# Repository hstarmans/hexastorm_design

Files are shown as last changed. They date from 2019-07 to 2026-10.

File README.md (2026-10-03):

# Hexastorm: Laser Scanner CAD

FreeCAD design files for **Hexastorm**, an open-hardware polygon laser direct imager (LDI) for PCB lithography and laser scanning.

* **Documentation & Theory**: [Open hardware fast high resolution laser (RepRap Wiki)](https://reprap.org/wiki/Open_hardware_fast_high_resolution_LASER)
* **Electronics & Firmware**: [firestarter (GitHub)](https://github.com/hstarmans/firestarter)
* **Optical Simulation**: [opticaldesign (GitHub)](https://github.com/hstarmans/opticaldesign)

<p align="center">
  Hexastorm Base Configuration (without cylinder lenses)
  Hexastorm with Cylinder Lenses
  <br>
  <em>Left: Base configuration (no cylinder lenses). Right: Configuration with CL1 saddle bridge and CL2 lens.</em>
</p>

---

## Design Overview

* **Optical Configurations (Base vs. Cylinder Lens Upgrade)**:

  * **Base (no cylinder lenses)**: Focussed beam goes directly from the laser diode through the polygon prism into a small spot. Lower component count, but results in an elliptical beam spot.
  * **With Cylinder Lenses**: Adding CL1 (mounted in saddle bridge `sk_bridge_pcb`) and CL2 circularizes the beam spot and optically cancels facet tilt errors from the rotating prism. The beam is collimated when it leaves the laserdiode.
* **Prism Drive & Motor Support**:

  * Typically, a refurbished sharp AR160 polygon mirror motor is used.
  * However, a  PCB motor (`mirrormotor.FCStd` / `pcbmotorasm`) with stator coils etched into PCB copper (driven by [firestarter](https://github.com/hstarmans/firestarter)) can also be used for laser scanning.

<p align="center">
  Hexastorm Planar PCB Motor and Internal Layout
</p>

* **Chassis**: Tab-and-slot FR4 PCB panels soldered at the seams.
* **Maxwell Kinematic Dock**:
  * Toolhead mount using 3 radial V-grooves on the scanhead PCB mating with 3 captive Ø 8.0 mm steel bearing balls on the dock base.
  * Clamped by 3 pairs of Ø 8.0 mm × 1.0 mm N52 magnets (~17 N pull, 0.40 mm magnet air gap).
  * PCB separation is 2.40 mm when docked.
  * Mates with [maxwell_dock.kicad_pcb](file:///home/hexastorm/Documents/hardware/firestarter/lasermodule/maxwell_dock/maxwell_dock/maxwell_dock.kicad_pcb). Mounting to a CNC 3018 or extrusion frame requires an adapter plate.

<p align="center">
  Hexastorm Maxwell Kinematic Dock Interface
</p>

* **KiCad Integration**: Board outlines and aperture cutouts in FreeCAD sync directly to KiCad `Edge.Cuts` via KiCad StepUp.

---

## Repository Structure

```text
├── FreeCAD files/
│   ├── assembly_compact_new.FCStd   # Main assembly (FreeCAD 1.0)
│   ├── mirrormotor.FCStd            # Polygon prism and PCB motor assembly
│   └── ArducamUC621/                # Calibration & profiling fixtures
├── Images/
│   ├── freecadpic_base.png          # Base configuration (no cylinder lenses)
│   ├── freecadpic.png               # Configuration with cylinder lenses
│   ├── pcb_motor_view.png           # Internal layout with planar PCB motor and rotor
│   └── kinematic_dock_view.png      # Kinematic dock underside view
├── AGENTS.md                        # CAD assistant & pair-programming guidelines
└── README.md
```

---

## CAD Environment

### 1. Git LFS

This repository stores `.FCStd` files and images in Git LFS. Run before cloning:

```bash
git lfs install
git clone https://github.com/hstarmans/hexastorm_design.git
```

*(If cloned without LFS, run `git lfs pull` inside the repository).*

### 2. FreeCAD Requirements

* **FreeCAD**: 1.0 or higher.
* **Workbenches**:
  * Assembly (built-in FreeCAD 1.0)
  * PartDesign
  * Fasteners Workbench
  * KiCad StepUp

---

## Optical Simulation & Ray Tracing

Ray tracing and optical verification are handled by [opticaldesign](https://github.com/hstarmans/opticaldesign) (`pyoptools` and `prisms.cad_verifier`).

Run with FreeCAD open:

```bash
cd path/to/opticaldesign
uv run python -m prisms.cad_verifier
```

This traces rays through the diode, lenses, polygon facets, and mirror, and writes rays into FreeCAD under `Simulation/Rays`.

---

## Reference Videos

* [Assembly 4 Design Overview (Legacy)](https://youtu.be/jhr6iEazbQk)
* [Optical Simulation Walkthrough](https://youtu.be/kekMkjqzRjE)

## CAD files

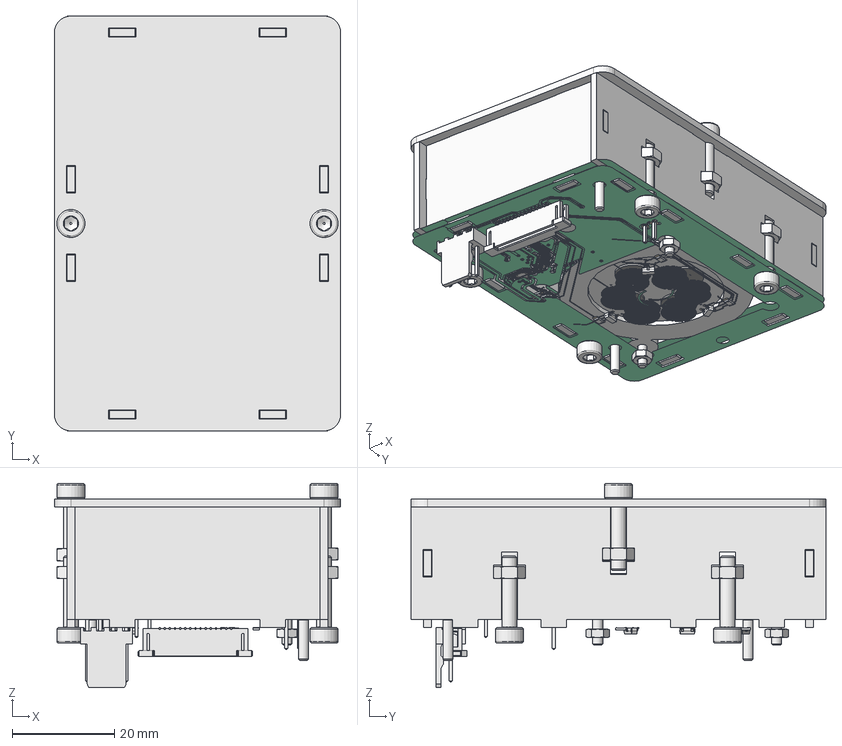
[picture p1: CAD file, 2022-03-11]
FreeCAD files/assembly_compact.FCStd
56.0 x 81.2 x 39.9 mm
M2x8-Screw066
M2x8-Screw067
topPads_87
topTracks_87
topZones_87
botPads_87
botTracks_87
botZones_87
C1_C_0805_2012Metric_00005d37801c x 9
J6_Molex_AE_6410_02A_00005d378133
R2_R_0805_2012Metric_00005d37818e x 15
U1_DFN-8-1EP_2x2mm_Pitch0.5mm_00005d3781c2
U2_CircuitWorks-SO-8_00005d3781d2
F2_Fuse_1206_3216Metric_000060f6f7c8 x 3
U5_SOT_353_SC_70_5_8d7aa654a458 x 2
U3_UQFN-16-1EP_3x3mm_Pitch0.5mm_772bcda8c549
J2_C-1-1734248-5_000060f44a9a
J1_Molex_AE_6410_04A_5e5622cabe99
U6_SOT_23_ee3f73b8ded8 x 3
M3x14-Screw1328
M3x14-Screw1329
M3x14-Screw1330
M3x14-Screw1331
M3-Nut1678
M3-Nut1675
M3-Nut1677
M3-Nut1676
support_body
M2x14-Screw
M2x14-Screw001
M2-Nut858
M2-Nut859
prismbody
spacersolid
laserdiodebasesolid
laserdiodebackplatesolid
M2x8-Screw
M2x8-Screw008
M2x8-Screw007
M2x8-Screw006
ringsolid
PadBody
magnet007 x 4
D1_BPW_34_S_20180209_geometry_000060f4e1a5
J1_PinHeader_1x02_P254mm_Horizontal_915322ff12bd
Pcb_323e002
rightside_plate x 2
back_plate
front_plate
PocketBody002
M3x14-Screw1322
M3x14-Screw1323
M3-Nut
M3-Nut1670

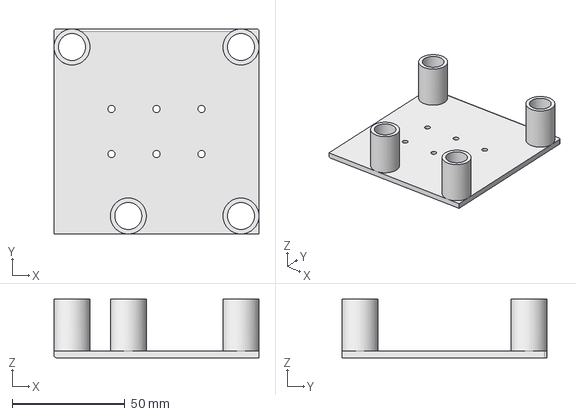
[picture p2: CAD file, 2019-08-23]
FreeCAD files/felix_mount.FCStd
91.0 x 91.0 x 26.0 mm

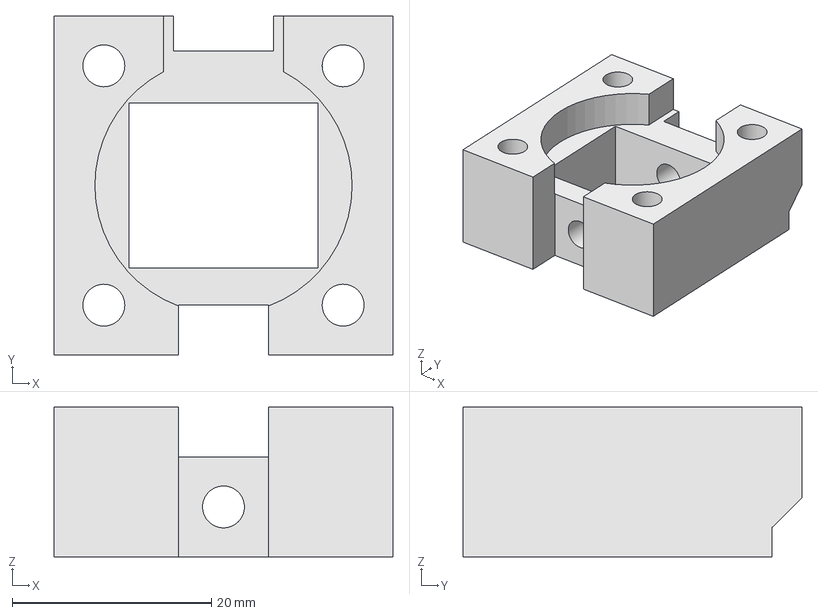
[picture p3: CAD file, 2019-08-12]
FreeCAD files/ueye_front.FCStd
34.0 x 34.0 x 15.0 mm

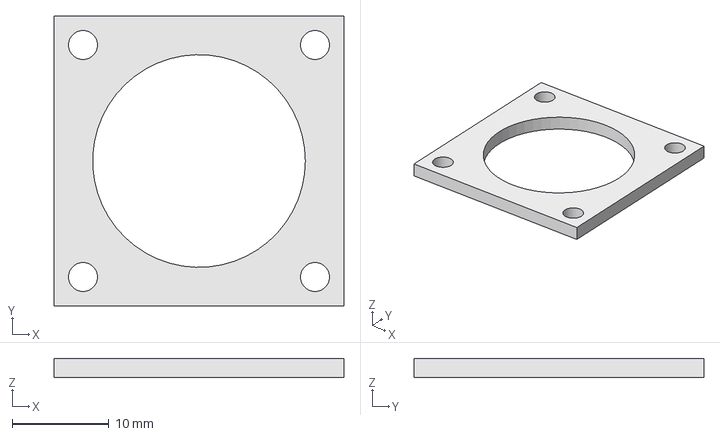
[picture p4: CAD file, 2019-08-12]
FreeCAD files/ueye_cap.FCStd
30.0 x 30.0 x 2.00 mm

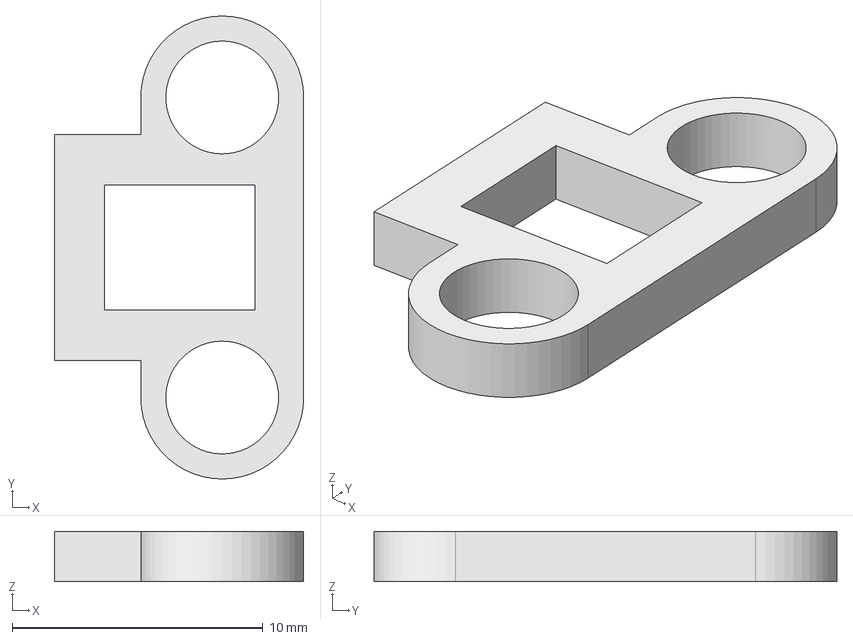
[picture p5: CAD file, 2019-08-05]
FreeCAD files/photodiode_cap.FCStd
9.95 x 18.5 x 2.00 mm

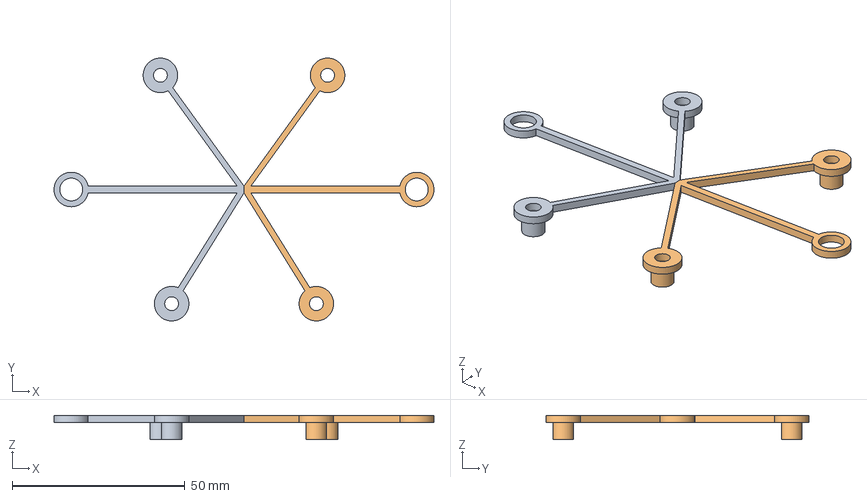
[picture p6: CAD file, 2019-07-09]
FreeCAD files/beaglebone_fixture.FCStd
110.0 x 76.1 x 7.00 mm
Pad002 (Mirror #1)

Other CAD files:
FreeCAD files/ArducamUC621/lensassembly.FCStd
FreeCAD files/assembly_compact_new.FCStd
FreeCAD files/cnc3018_case.FCStd
FreeCAD files/ArducamUC621/arducamUC621base.FCStd
FreeCAD files/cnc3018_pro.FCStd
FreeCAD files/ArducamUC621/ueye_postholder.FCStd
FreeCAD files/mirrormotor.FCStd
renders/hexastorm_assembly.blend

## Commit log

2019-06-05 added current repository of freecad design files, stls and solidpython
    [bovenkant.fcstd, onderkant.fcstd]
2019-06-05 added stls
    added stls made with solidedge
    [aspheric_25mm_mount.stl, aspheric_75mm_mount.stl, baseplate.stl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]
2019-06-06 added standoff design and considerations
    [standoff.FCStd]
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2019-06-12 added start baseplate
    [baseplate.FCStd]
2019-06-17 added aspherical lens1
    [aspherical_lens1.FCStd, baseplate.FCStd, standoff_polygonmirror.FCStd]
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2019-06-18 added sketch lens2
    [aspherical_lens2.FCStd]
2019-06-18 added aspherical lens with mirror holder
    [aspherical_lens2.FCStd]
2019-06-18 added photodiode cap and holder
    [photodiode_cap.FCStd, photodiode_holder.FCStd]
2019-06-19 updated cylindrical lens 1
    [aspherical_lens1.FCStd, cylindrical_lens1.FCStd]
2019-06-19 changed second cylindrical lens
    [cylindrical_lens2.FCStd]
2019-06-19 removed lens
    [aspherical_lens2.FCStd]
2019-06-19 prepared baseplate and standoff for first test
    [baseplate.FCStd, cylindrical_lens1.FCStd, standoff_polygonmirror.FCStd]
2019-06-20 height laserdiode should be set from the top
    [baseplate.FCStd, ofl510v3_support.FCStd, standoff_polygonmirror.FCStd]
2019-06-27 made some major changes to cylindrical lens2
    still needs testing
    [baseplate.FCStd, cylindrical_lens1.FCStd, cylindrical_lens2_trial2.FCStd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]
2019-07-09 added atx holders, fixture and modified baseplate
    [atxholder_back.FCStd, atxholder_front.FCStd, baseplate.FCStd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]
2019-07-24 updated bom list and added standoff board
    [standoff_alignmentboard.FCStd]
2019-07-24 added new base for photodiode and modified cylindrical lens so it can be positioned
    [cylindrical_lens2.FCStd, cylindrical_lens2_trial2.FCStd, photodiode_base.FCStd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]
2019-08-05 added latest changes, second cylindrical lens holder should have correct dimensions
    [cylindrical_lens2_trial2.FCStd, photodiode_base.FCStd, photodiode_cap.FCStd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]
2019-08-12 updated designs
    [cylindrical_lens2_trial2.FCStd, ueye_cap.FCStd, ueye_front.FCStd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]
2019-08-19 started maxing enclosure suitable for laser cutting
    [assembly.FCStd, back.step, back_module.FCStd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]
2019-08-19 modified box, too few room to move first cylindrical lens
    [assembly.FCStd, bottem.step, box_2.FCStd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]
2019-08-20 forgot to save latest changes
    [box_2.FCStd]
2019-08-22 added mount to felixprinter, changed height lasertube
    [felix_mount.FCStd, lasertube_support.FCStd]
2019-08-23 enlarged internal diameter felixmount to 6 mm
    [felix_mount.FCStd]
2019-08-23 updated box
    [box_2.FCStd]
2019-09-16 changed basepost
    [photodiode_basepostm6.FCStd]
2019-09-18 cleaned up repository for hackaday 2019 semi-finals
    [aspheric_25mm_mount.stl, aspheric_75mm_mount.stl, assembly.FCStd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]
2019-10-21 fixed thickness
    [box_2.FCStd]
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2020-08-17 added fixture for rasp
    [raspberry_fixture.FCStd]
2020-12-15 improved box
    [assembly.FCStd, assembly_interlock.FCStd, back.step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]
2020-12-18 updated box, improved assembly
    most parts are now maintaned in assembly
    [arducamUC621base.FCStd, arducamUC621lensholder.FCStd, assembly.FCStd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]
2020-12-18 removed steps
    [back.step, bottem.step, front.step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]
2020-12-18 removed screwbase
    [screwbase2_cylinderlens1.FCStd, screwbase_cylinderlens1.FCStd]
2021-01-05 created assembly
    [48353.FCStd, arducamUC621base.FCStd, arducamUC621lensholder.FCStd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]
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2021-06-20 added optical simulations
    [fullassembly.FCStd]
2021-07-28 updated assemlby
    [fullassembly.FCStd]
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2021-08-04 updated simulation and improved positions
    [fullassembly.FCStd]
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2021-08-06 reduced width of assembly
    might crash in optical simulation, still needs to be checked
    [fullassembly.FCStd]
2021-09-02 added new laser diode module
    [fullassembly.FCStd]
2021-09-04 fixed top
    [fullassembly.FCStd]
2021-09-05 updated assembly and design
    [fullassembly.FCStd]
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2021-10-05 alignment tool used for mounting prism assembly reduced in size, cross scan error should be lower
    [alignmenttool_prism.FCStd, fullassembly.FCStd]
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2021-10-13 parameterized assembly fixed baseplate updated felix mount for new assembly added new motor support board
    [felix_mount.FCStd, fullassembly.FCStd, motorsupport.FCStd]
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2021-10-14 added raytrace and updated params
    [fullassembly.FCStd]
2021-10-15 made the board a bit wider
    [fullassembly.FCStd]
2021-10-31 increased slit length protrusions are more curved then expected due to laser cutting
    [fullassembly.FCStd]
2021-12-28 number of magnets should equal poles in motor
    [felix_mount.FCStd, prism_motor.FCStd]
2022-02-18 updated new prism motor design to teflon
    [prism_motor.FCStd]
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2022-03-01 added magnet holder to assembly
    [assembly_compact.FCStd]
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2022-03-10 assembly should be ready for fab
    [assembly_compact.FCStd]
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2024-09-27 changed to LTFS, improved mirror motor
    [mirrormotor.FCStd]
2024-10-02 assembly supports both pcb and mirrror
    [assembly_compact_new.FCStd]
2024-10-17 changed optics, cylinder lens, box dimensions
    [assembly_compact_new.FCStd]
2024-10-24 updated assembly with latest changes
    [assembly_compact_new.FCStd]
2024-11-03 render of finalized design
    [assembly_compact_new.FCStd, mirrormotor.FCStd]
2024-11-07 Design tweaks for new hardware update
    [assembly_compact_new.FCStd]
2024-11-22 reduced length box under 100 mm
    [assembly_compact_new.FCStd]
2024-11-25 state design submitted to pcbway
    [assembly_compact_new.FCStd]
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2026-08-24 updated mirror holder, connector plate, moved to freecad 1.1.3
    [assembly_compact_new.FCStd]
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2026-09-29 increased laserheight with 1.5 mm<< placed back sketches constraints
    [assembly_compact_new.FCStd, mirrormotor.FCStd]
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2026-10-03 updated readme, more tweaks to design
    [assembly_compact_new.FCStd, mount_cnc3018_oldboard.FCStd]
2026-10-05 step model fix for photodiode, added mount for cnc3018pro
    [assembly_compact_new.FCStd, mount_cnc3018_oldboard.FCStd]
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2026-10-07 Add hexastorm_assembly.blend to renders with Git LFS
    [hexastorm_assembly.blend]
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
